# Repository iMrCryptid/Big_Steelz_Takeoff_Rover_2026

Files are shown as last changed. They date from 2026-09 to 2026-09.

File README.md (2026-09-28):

# Big Steelz Takeoff Rover 2026

<!-- Add a photo of the finished rover to Media/Photos, then uncomment the line below and match the file name -->
<!-- ![Big Steelz rover](Media/Photos/rover.jpg) -->

A six wheel, remote controlled rover with rocker bogie suspension and a four servo arm and gripper. It was designed, 3D printed, wired, and programmed by a team of five for the **TMU Takeoff Rover Building Competition** (February to May 2026), where it took ** first place in the Guess the Word challenge**. It is driven from a phone over WiFi.

This repo documents how the rover was built: the CAD, the electronics, the code, and what we learned along the way.

<!-- Add a demo video here, e.g. [Watch it run](https://youtube.com/...) -->

## Design overview

The competition had three challenges: a time trial over bumps and around walls, a block sorting match where blocks are placed on a three level shelf, and a word guessing game using a laser pointer mounted on the rover. The rover needed to handle all three, so it was built around four subsystems.

**Suspension.** A rocker bogie layout, the same design used on Mars rovers. Each side has a rocker and a bogie carrying three wheels, which pivot so all six wheels stay in contact with the ground over uneven terrain, without any springs.

**Body.** Houses the ESP32, motor driver, and battery, with a removable lid for access and a mount for the arm.

**Arm.** Three servo joints carrying the gripper. It was also where we mounted the laser pointer for Guess the Word: the servos move in small 2° steps per button press, which let the pilot make fine adjustments to point at individual letters instead of steering the whole rover onto a target.

**Gripper.** A servo driven pincher used to pick up and place blocks.

## Hardware

| Component | Details |
|---|---|
| Microcontroller | ESP32 DevKit V1 (WROOM 32) |
| Motor driver | L298N dual H bridge |
| Drive | 6 TT gear motors (3 to 6 V), 3 per side |
| Suspension | Rocker bogie |
| Arm | 3 MG996r servos |
| Gripper | 1 MG90s servo |
| Power | 7.4 V 5200 mAh 2S LiPo |
| Structure | 3D printed in PLA |

## Control

The ESP32 runs its own WiFi access point. Connect a phone to it and open `192.168.4.1` to load the control page.

* **Drive mode:** forward, reverse, and turning; arm locked
* **Arm mode:** arm servos active; drive motors stopped and locked
* **Claw:** open and close in either mode
* **Stop:** cuts both drive motors immediately

Splitting control into two modes keeps the pilot from accidentally driving while positioning the arm, which matters when placing blocks or aiming the laser.

## Repository layout

```
CAD/STL/
├── Arm/          arm base and segments
├── Body/         body, lid, mount, cap
├── Gripper/      base, mount, pincher, rod, servo horn parts, cap
└── Suspension/   rockers, bogie, caps
Code/             ESP32 firmware (Arduino)
Electronics/      wiring diagram and pinout
Media/            photos and video
```

GitHub shows a 3D preview of any STL file in the browser, so you can inspect parts without downloading them.

## Electronics

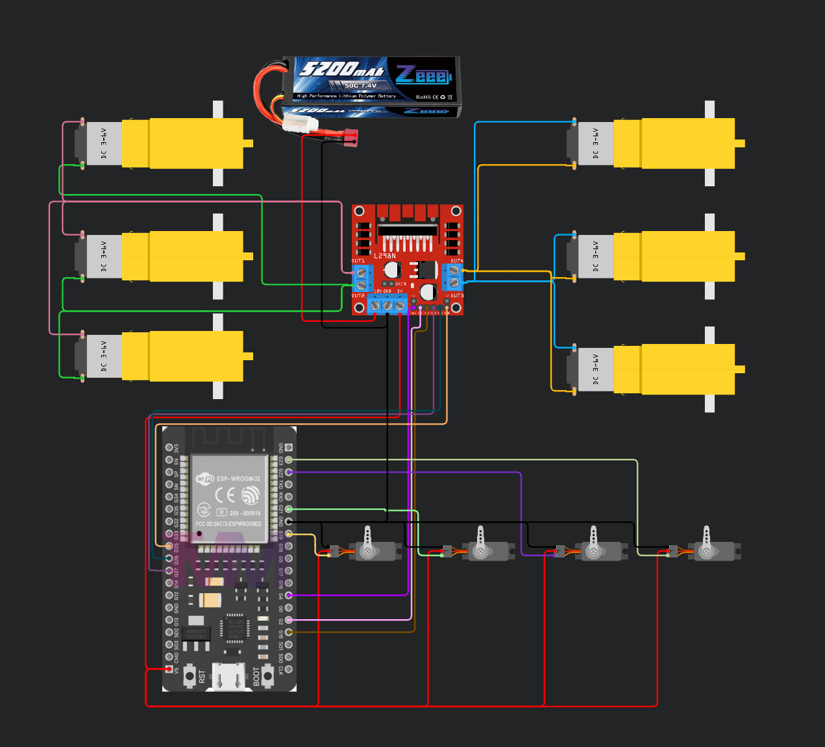
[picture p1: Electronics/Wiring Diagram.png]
Wiring diagram


The battery feeds the L298N, which drives three motors per side. The L298N's onboard 5 V regulator powers the ESP32 and all four servos, and every ground is tied together. Every pin assignment is listed in [`Electronics/pinout.md`](Electronics/pinout.md).

Wire colours on the motor leads show orientation only; the L298N reverses polarity on its outputs to change direction.

## Building it

* All parts are printed in PLA.
* Print the **cap** parts in each subsystem folder. They secure joints where the original tolerances came out loose, and the parts will not hold together without them.
* Set your own network name and password at the top of `Code/main.ino` before uploading.
* Upload with the Arduino IDE using the ESP32 board package and the `ESP32Servo` library.

## Team

| Member | Contributions |
|---|---|
| **Jeffrey Acquah** (team lead) | Designed and finalized the gripper and suspension; finalized the arm; designed all tolerance caps and reprinted parts as needed; responsible for wiring the full rover; led troubleshooting across the full program code; guesser in Guess the Word |
| **Kiara** | Programmed the drivetrain; drew diagrams for the preliminary round; helped assemble, wire, and troubleshoot |
| **Josiah** | Designed arm segments and the gripper mount; helped finalize the body mount; built an enclosure for an ultrasonic sensor; helped assemble; main pilot |
| **Pravani** | CAD drawings and most of the research for the preliminary round; coded the controller UI and WiFi connection; helped assemble |
| **Eric** | Designed the body and lid; programmed the arm; helped assemble; copilot, and pilot after Josiah left; pilot in Guess the Word|

## What We'd change

* **Tolerances.** Many printed joints came out too loose, so I designed caps to secure them. Next time I'd print small test pieces first to dial in clearances before printing full parts.
* **Servo power.** The L298N's onboard 5 V regulator powers the ESP32 and all four servos. Servo current spikes can brown out the ESP32. A separate 5 V buck converter for the servos would fix this.
* **Motor driver.** Six motors on one L298N is close to its limit, and it wastes a lot of power as heat. A modern MOSFET based driver would be more efficient.
* **Speed control.** The enable pins are switched fully on or off, so the motors only run at full speed. Using PWM on ENA and ENB would allow slower, more precise driving.
* **Pin choice.** The left motor uses GPIO 2 and 15, which are ESP32 boot strapping pins and can cause upload problems. Moving them to pins like 32 and 33 avoids that.
* **Aiming.** The 2° servo step worked well for the laser, but we found it rather than tuned it. Next time I'd make the step size adjustable from the control page.

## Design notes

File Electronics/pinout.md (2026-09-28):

# Pinout

Microcontroller: ESP32 DevKit V1 (WROOM 32)
Motor driver: L298N dual H bridge
Servos: 4 total, 3 for the arm and 1 for the claw

## Drive motors

| Signal | ESP32 GPIO | Connects to | Notes |
|---|---|---|---|
| IN1 | 2 | Motor driver IN1 | Left motor direction |
| IN2 | 15 | Motor driver IN2 | Left motor direction |
| ENA | 4 | Motor driver ENA | Left motor enable (on/off only, see notes) |
| IN3 | 27 | Motor driver IN3 | Right motor direction |
| IN4 | 26 | Motor driver IN4 | Right motor direction |
| ENB | 25 | Motor driver ENB | Right motor enable (on/off only, see notes) |

### Direction logic

| Left motor | IN1 | IN2 | ENA |
|---|---|---|---|
| Forward | HIGH | LOW | HIGH |
| Reverse | LOW | HIGH | HIGH |
| Stop | LOW | LOW | LOW |

The right motor follows the same pattern with IN3, IN4, and ENB.

## Servos

| Servo | ESP32 GPIO | Function | Start position | Allowed range |
|---|---|---|---|---|
| S1 | 19 | Arm joint 1 | 180° | 0° to 180° |
| S2 | 21 | Arm joint 2 | 90° | 0° to 180° |
| S3 | 22 | Arm joint 3 | 90° | 0° to 180° |
| S4 | 23 | Claw | 45° | 10° (closed) to 90° (open) |

All servos use a 500 to 2400 μs pulse range. Each button press moves a servo 2°.

## Power

| Supply | Voltage | Powers |
|---|---|---|
| 2S LiPo battery | 7.4 V | L298N motor input (12V terminal), which drives all 6 motors |
| L298N onboard regulator (5V terminal) | 5 V | ESP32 (V5 pin) and all 4 servos |

All grounds (battery, L298N, ESP32, servos) must be tied together, or the motor signals from the ESP32 have no reference.

## Control

The ESP32 runs as a WiFi access point. Connect a phone to its network and open `192.168.4.1` in a browser to get the control page.

* **Drive mode:** drive buttons active, arm servos locked
* **Arm mode:** arm servos active, drive motors locked and stopped
* **Claw:** works in both modes
* **Stop:** cuts both drive motors

## Notes

* **ENA and ENB are driven fully on or off,** not with PWM, so the motors only run at full speed. Switching these to PWM would allow speed control.
* **GPIO 2 and GPIO 15 are ESP32 boot strapping pins.** They can interfere with uploading or booting if the motor driver pulls them the wrong way at power up. GPIO 2 also drives the onboard LED on most boards, so the LED lights when the left motor runs forward. If uploads ever fail, unplug the motor driver and try again, or move these to safer pins such as 32 and 33.

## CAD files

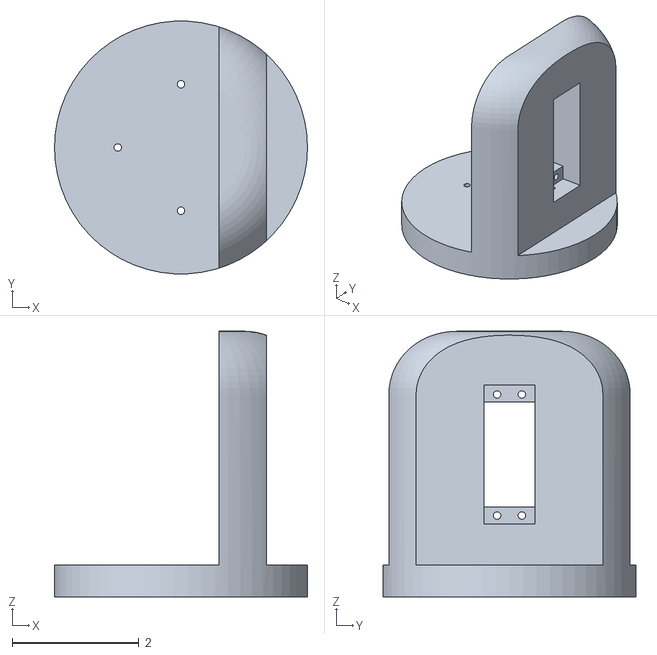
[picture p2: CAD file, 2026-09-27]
CAD/STL/Arm/Arm Base.stl
4.00 x 3.99 x 4.20

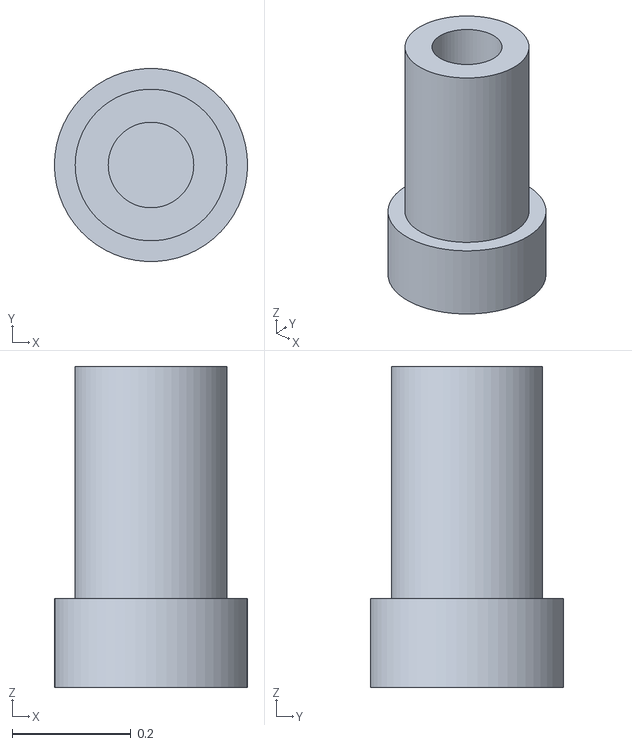
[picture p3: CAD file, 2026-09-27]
CAD/STL/Body/Body Cap.stl
0.325 x 0.325 x 0.54

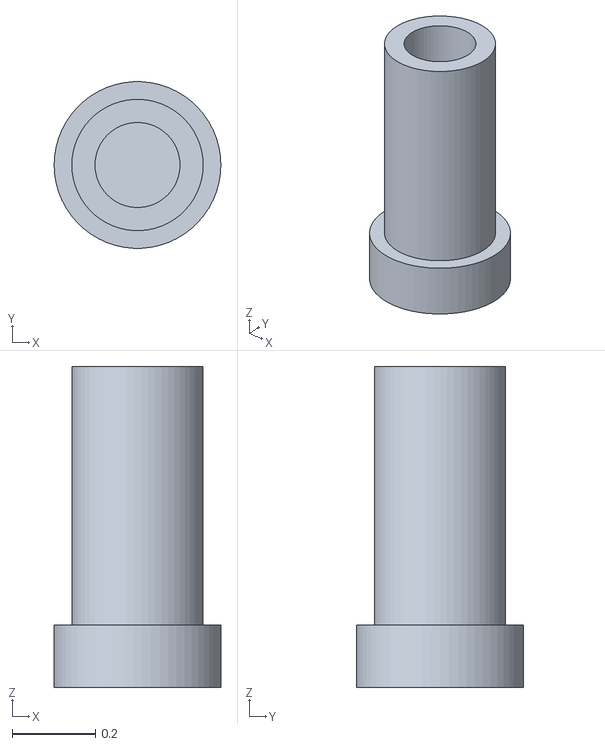
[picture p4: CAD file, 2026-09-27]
CAD/STL/Gripper/Gripper Cap.stl
0.4 x 0.399 x 0.77

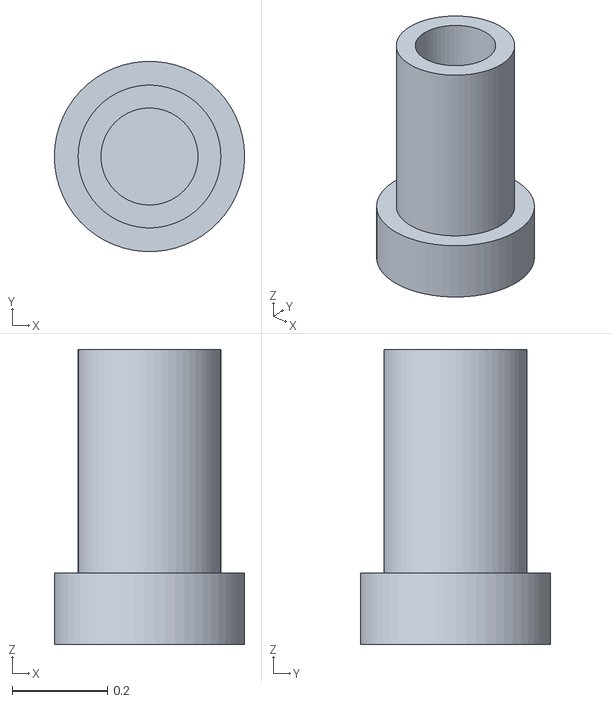
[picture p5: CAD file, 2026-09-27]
CAD/STL/Suspension/Bogie Cap.stl
0.4 x 0.399 x 0.62

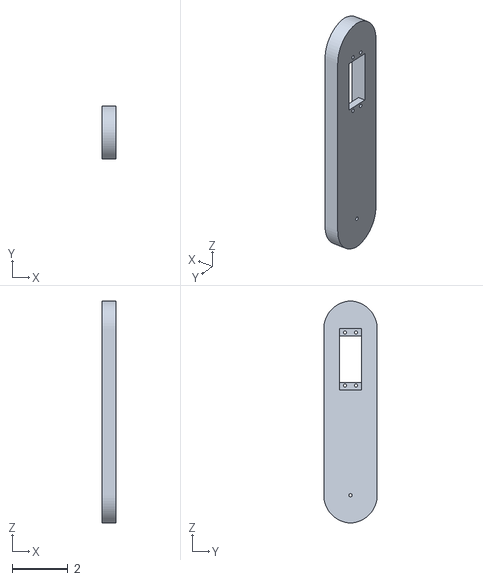
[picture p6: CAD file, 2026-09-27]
CAD/STL/Arm/Arm Segment.stl
0.5 x 1.93 x 8.00

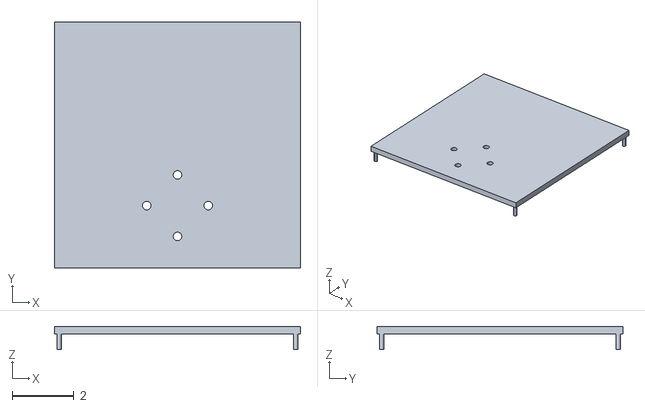
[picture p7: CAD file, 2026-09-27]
CAD/STL/Body/Body Lid.stl
8.00 x 8.00 x 0.75

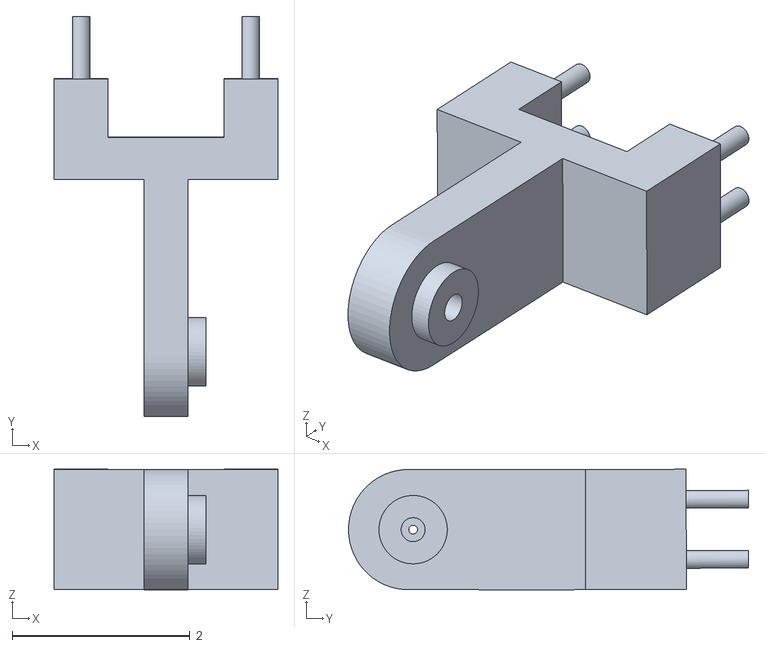
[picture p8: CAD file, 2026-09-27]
CAD/STL/Gripper/Gripper Mount.stl
2.52 x 4.50 x 1.36

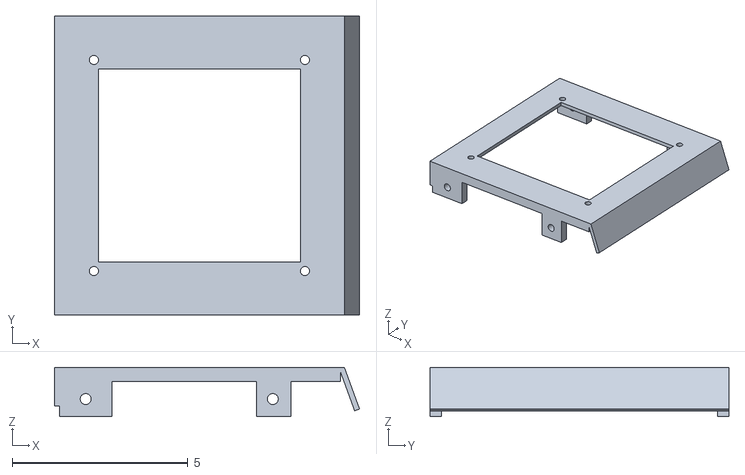
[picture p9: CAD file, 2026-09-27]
CAD/STL/Body/Body Mount.stl
8.68 x 8.50 x 1.40

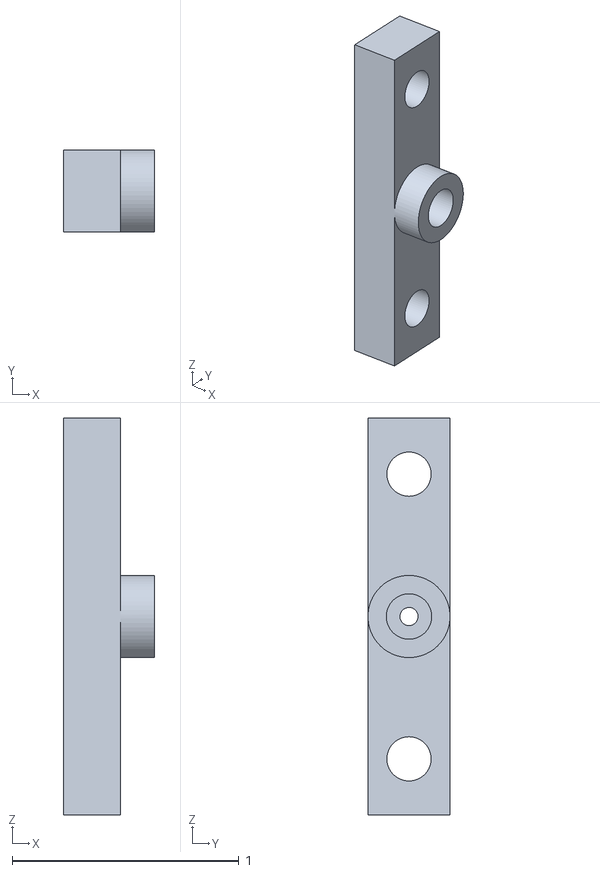
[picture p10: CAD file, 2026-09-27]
CAD/STL/Gripper/MG90s Servo horn.stl
0.4 x 0.362 x 1.75

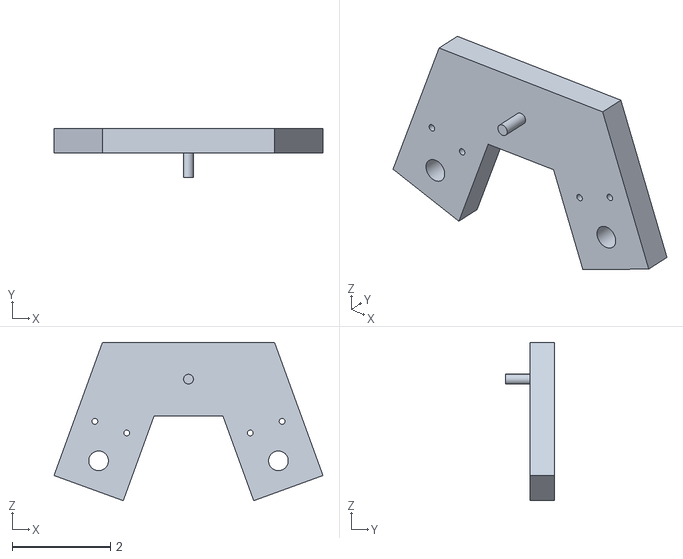
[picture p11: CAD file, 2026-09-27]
CAD/STL/Suspension/Bogie.stl
5.47 x 1.00 x 3.22

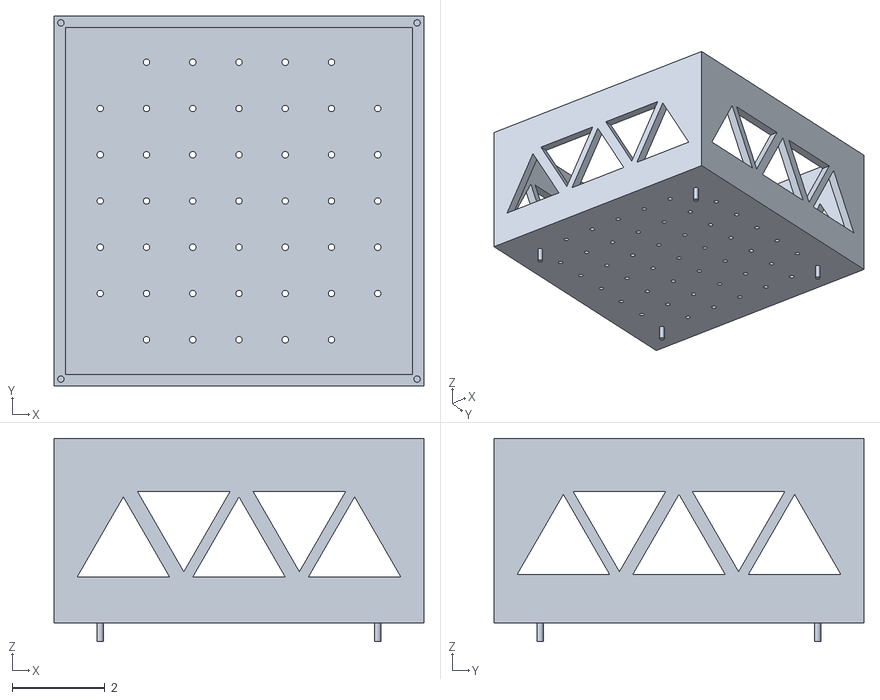
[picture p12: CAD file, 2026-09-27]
CAD/STL/Body/Body.stl
8.00 x 8.00 x 4.40

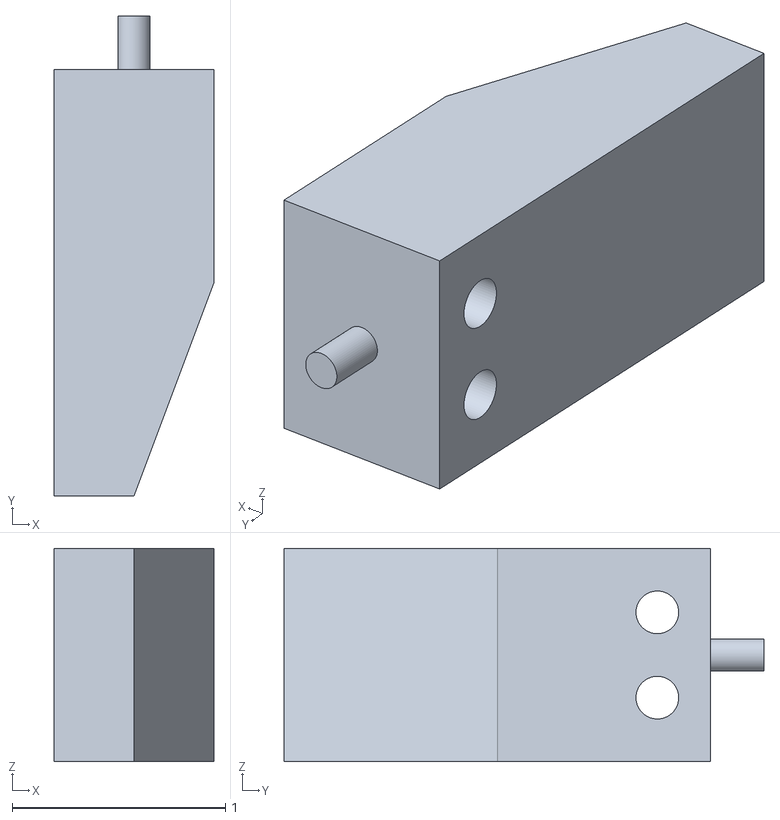
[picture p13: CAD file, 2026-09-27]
CAD/STL/Gripper/Pincher.stl
0.75 x 2.25 x 1.00

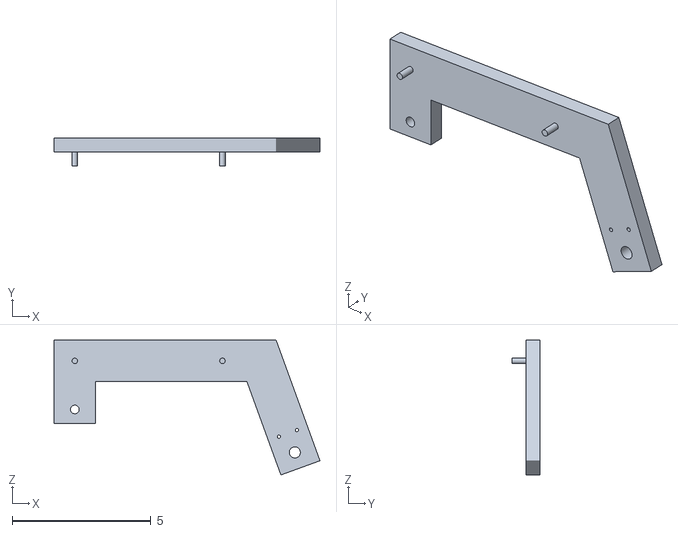
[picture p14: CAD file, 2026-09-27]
CAD/STL/Suspension/Right Rocker.stl
9.58 x 1.00 x 4.86

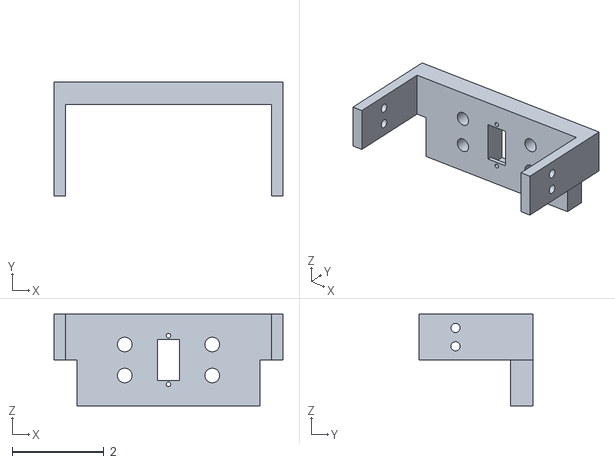
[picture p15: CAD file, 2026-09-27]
CAD/STL/Gripper/Gripper Base.stl
5.00 x 2.50 x 2.00

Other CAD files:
CAD/STL/Suspension/Rocker Cap.stl
CAD/STL/Suspension/Left Rocker.stl
CAD/STL/Gripper/Rod.stl
CAD/STL/Gripper/Servo Horn Extension.stl

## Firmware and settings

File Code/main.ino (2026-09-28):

#include <WiFi.h>
#include <WebServer.h>
#include <ESP32Servo.h>

// ================= WIFI =================
const char* ssid = "WIFI_NAME";
const char* password = "WIFI_PASSWORD";

WebServer server(80);

// ================= FUNCTION PROTOTYPES =================
void handleRoot();
void handleMove();
void handleServo();
void handleMode();
void emergencyStop();

// ================= MOTORS =================
const int in1 = 2;
const int in2 = 15;
const int enA = 4;

const int in3 = 27;
const int in4 = 26;
const int enB = 25;

// ================= SERVOS =================
Servo s1, s2, s3, s4;

const int p1 = 19;
const int p2 = 21;
const int p3 = 22;
const int p4 = 23;

// Safe initial values (YOU manually adjust later)
int pos1 = 180;
int pos2 = 90;
int pos3 = 90;
int pos4 = 45;

// smoothing helper
int last3 = 90;

const int stepSize = 2;

// ================= MODES =================
enum Mode {
  DRIVE_MODE,
  ARM_MODE
};

Mode mode = DRIVE_MODE;

// ================= MOTOR CONTROL =================
void setMotors(int left, int right) {

  // LEFT
  if (left > 0) {
    digitalWrite(in1, HIGH);
    digitalWrite(in2, LOW);
    digitalWrite(enA, HIGH);
  } else if (left < 0) {
    digitalWrite(in1, LOW);
    digitalWrite(in2, HIGH);
    digitalWrite(enA, HIGH);
  } else {
    digitalWrite(in1, LOW);
    digitalWrite(in2, LOW);
    digitalWrite(enA, LOW);
  }

  // RIGHT
  if (right > 0) {
    digitalWrite(in3, HIGH);
    digitalWrite(in4, LOW);
    digitalWrite(enB, HIGH);
  } else if (right < 0) {
    digitalWrite(in3, LOW);
    digitalWrite(in4, HIGH);
    digitalWrite(enB, HIGH);
  } else {
    digitalWrite(in3, LOW);
    digitalWrite(in4, LOW);
    digitalWrite(enB, LOW);
  }
}

// ================= EMERGENCY STOP =================
void emergencyStop() {
  setMotors(0,0);

  // optional safety micro-reset for servos (prevents runaway jitter)
  delay(50);
}

// ================= ROOT PAGE =================
const char page[] PROGMEM = R"rawliteral(

<!DOCTYPE html>
<html>
<head>
<meta name="viewport" content="width=device-width, initial-scale=1">

<style>
*{
  user-select:none;
  -webkit-user-select:none;
  -ms-user-select:none;
  -webkit-tap-highlight-color:transparent;
  touch-action:manipulation;
}

body{
  font-family:Arial;
  background:#111;
  color:white;
  text-align:center;
}

button{
  width:120px;
  height:55px;
  margin:6px;
  font-size:18px;
  border:none;
  border-radius:10px;
  background:#444;
  color:white;
}

button:active{
  background:#00b7ff;
}
</style>

<script>

let x=0,y=0;
let driveTimer=null;

// ================= DRIVE =================
function press(axis,val,e){
  e.preventDefault();

  if(axis=='x') x=val;
  if(axis=='y') y=val;

  if(!driveTimer){
    driveTimer=setInterval(()=>{
      fetch(`/move?x=${x}&y=${y}`);
    },120);
  }
}

function release(e){
  e.preventDefault();

  x=0;y=0;

  clearInterval(driveTimer);
  driveTimer=null;

  fetch(`/move?x=0&y=0`);
}

// ================= SERVO =================
let servoTimer=null;
let sid=0;
let sdir="";

function servoDown(id,dir,e){
  e.preventDefault();

  sid=id;
  sdir=dir;

  fetch(`/servo?id=${id}&dir=${dir}`);

  servoTimer=setInterval(()=>{
    fetch(`/servo?id=${sid}&dir=${sdir}`);
  },180);
}

function servoUp(e){
  e.preventDefault();
  clearInterval(servoTimer);
  servoTimer=null;
}

// ================= MODE =================
function mode(m){
  fetch(`/mode?mode=${m}`);
}

// ================= EMERGENCY =================
function stopAll(){
  fetch(`/stop`);
}

</script>
</head>

<body>

<h2>🚗 ROBOT CONTROL</h2>

<h3>Mode</h3>
<button onclick="mode('drive')">🚗 DRIVE</button>
<button onclick="mode('arm')">🤖 ARM</button>

<button onclick="stopAll()" style="background:#ff4444;">🛑 STOP</button>

<h3>Drive</h3>
<button onpointerdown="press('y',1,event)" onpointerup="release(event)">FWD</button>
<button onpointerdown="press('y',-1,event)" onpointerup="release(event)">REV</button>

<button onpointerdown="press('x',-1,event)" onpointerup="release(event)">LEFT</button>
<button onpointerdown="press('x',1,event)" onpointerup="release(event)">RIGHT</button>

<h3>Claw (always active)</h3>
<button onpointerdown="servoDown(4,'up',event)" onpointerup="servoUp(event)">OPEN</button>
<button onpointerdown="servoDown(4,'down',event)" onpointerup="servoUp(event)">CLOSE</button>

<h3>Arm (ARM MODE ONLY)</h3>
<button onpointerdown="servoDown(1,'up',event)" onpointerup="servoUp(event)">S1+</button>
<button onpointerdown="servoDown(1,'down',event)" onpointerup="servoUp(event)">S1-</button>

<button onpointerdown="servoDown(2,'up',event)" onpointerup="servoUp(event)">S2+</button>
<button onpointerdown="servoDown(2,'down',event)" onpointerup="servoUp(event)">S2-</button>

<button onpointerdown="servoDown(3,'up',event)" onpointerup="servoUp(event)">S3+</button>
<button onpointerdown="servoDown(3,'down',event)" onpointerup="servoUp(event)">S3-</button>

</body>
</html>

)rawliteral";

// ================= HANDLERS =================
void handleRoot() {
  server.send_P(200, "text/html", page);
}

// ================= MOVE =================
void handleMove() {

  if (mode != DRIVE_MODE) {
    server.send(200,"text/plain","ARM LOCKED");
    return;
  }

  int x = server.arg("x").toInt();
  int y = server.arg("y").toInt();

  int left = y;
  int right = y;

  if (x == -1) { left = y - 1; right = y + 1; }
  if (x == 1)  { left = y + 1; right = y - 1; }

  setMotors(constrain(left,-1,1), constrain(right,-1,1));

  server.send(200,"text/plain","OK");
}

// ================= SERVO =================
void handleServo() {

  int id = server.arg("id").toInt();
  String dir = server.arg("dir");

  int step = (dir == "up") ? stepSize : -stepSize;

  // CLAW ALWAYS ACTIVE
  if (id == 4) {
    pos4 = constrain(pos4 + step, 10, 90);
    s4.write(pos4);
    server.send(200,"text/plain","OK");
    return;
  }

  // ARM ONLY IN ARM MODE
  if (mode != ARM_MODE) {
    server.send(200,"text/plain","LOCKED");
    return;
  }

  if (id == 1) {
    pos1 = constrain(pos1 + step, 0, 180);
    s1.write(pos1);
  }

  if (id == 2) {
    pos2 = constrain(pos2 + step, 0, 180);
    s2.write(pos2);
  }

  if (id == 3) {
    pos3 = constrain(pos3 + step, 0, 180);

    if (abs(pos3 - last3) > 2) {
      s3.write(pos3);
      last3 = pos3;
    }
  }

  server.send(200,"text/plain","OK");
}

// ================= MODE =================
void handleMode() {

  String m = server.arg("mode");

  if (m == "drive") {
    mode = DRIVE_MODE;
    setMotors(0,0);
  }

  if (m == "arm") {
    mode = ARM_MODE;
    setMotors(0,0);
  }

  server.send(200,"text/plain","OK");
}

// ================= STOP =================
void handleStop() {
  emergencyStop();
  server.send(200,"text/plain","STOPPED");
}

// ================= SETUP =================
void setup() {

  Serial.begin(115200);

  pinMode(in1,OUTPUT);
  pinMode(in2,OUTPUT);
  pinMode(in3,OUTPUT);
  pinMode(in4,OUTPUT);
  pinMode(enA,OUTPUT);
  pinMode(enB,OUTPUT);

  setMotors(0,0);

  ESP32PWM::allocateTimer(0);
  ESP32PWM::allocateTimer(1);
  ESP32PWM::allocateTimer(2);
  ESP32PWM::allocateTimer(3);

  s1.attach(p1,500,2400);
  s2.attach(p2,500,2400);
  s3.attach(p3,500,2400);
  s4.attach(p4,500,2400);

  delay(600);

  s1.write(pos1);
  s2.write(pos2);
  s3.write(pos3);
  s4.write(pos4);

  WiFi.mode(WIFI_AP);
  WiFi.setSleep(false);
  WiFi.softAP(ssid,password);

  server.on("/",handleRoot);
  server.on("/move",handleMove);
  server.on("/servo",handleServo);
  server.on("/mode",handleMode);
  server.on("/stop",handleStop);

  server.begin();
}

// ================= LOOP =================
void loop() {
  server.handleClient();
}

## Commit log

2026-09-28 Rename Code/Screenshot 2026-09-27 210308.png to Wiring Diagram.png
2026-09-28 Rename Screenshot 2026-09-27 210308.png to Wiring Diagram.png
2026-09-28 Add full README and fill in pinout power section
    Claude-Session: https://claude.ai/code/session_013TbQn2YCkdKYGHwLgYNJ3Z
2026-09-28 Refocus README on the rover build, update wiring diagram, remove placeholders
    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
2026-09-28 Change arm and gripper servo models in README
    Updated specifications for arm and gripper servos in README.
